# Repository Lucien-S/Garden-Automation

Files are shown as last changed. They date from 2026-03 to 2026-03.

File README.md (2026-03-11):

# Garden Automation — ESP32

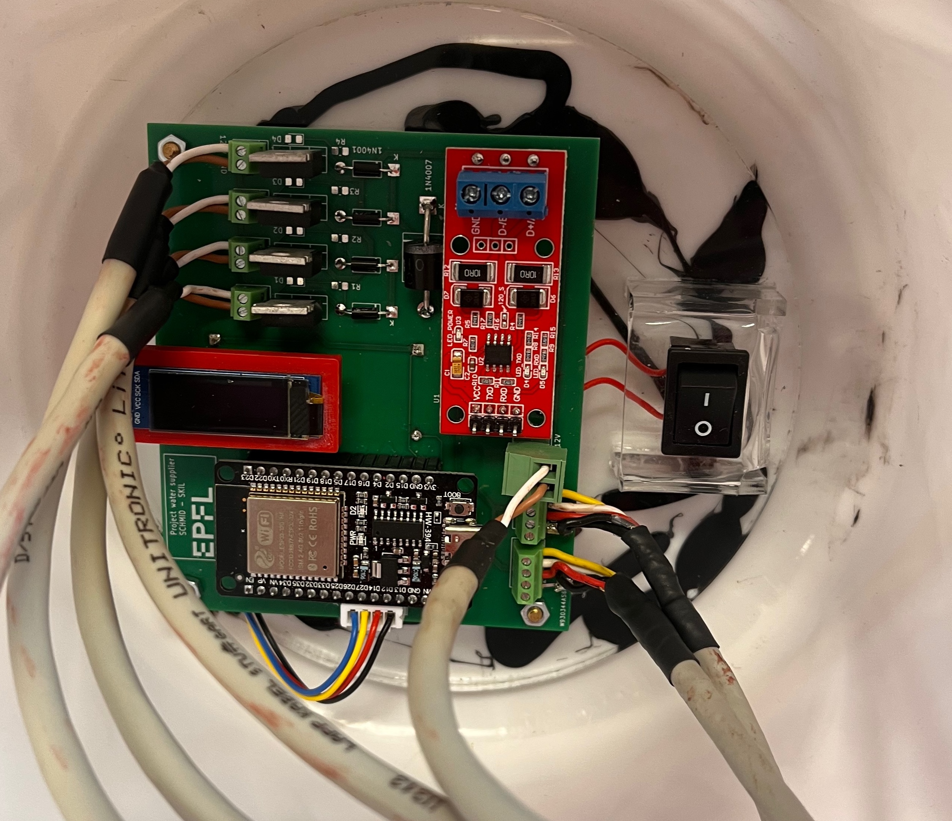
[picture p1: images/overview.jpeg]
PCB overview with cables to pumps and electrovannes


Automated garden watering system based on ESP32, soil moisture sensors (RS485/Modbus), solenoid valves, and MQTT over WiFi.

Youtube link: [ https://youtube.com/shorts/rQiWS8xde-I?feature=share ](https://youtu.be/8DQGsPcLfHw)

KiCad files are available in the folder /kicad

---

## Hardware

| Component | Details |
|---|---|
| MCU | ESP32-WROOM-32D |
| Moisture sensors | RS485 Modbus (x2), addresses 0x01 and 0x02 |
| Solenoid valves | 3× EV (EV1, EV2, EV3) driven via GPIO |
| Pump | 1× driven via GPIO |
| Display | SSD1306 OLED 128×32, I2C |
| Communication | WiFi SoftAP + MQTT |

### Pin Mapping

| Pin | Function |
|-----|---|
| GPIO 23 | Pump |
| GPIO 19 | EV1 |
| GPIO 22 | EV2 |
| GPIO 3 | EV3 |
| GPIO 32 | OLED SDA |
| GPIO 33 | OLED SCL |
| GPIO 16 | RS485 RX |
| GPIO 17 | RS485 TX |

---

## Software

### Dependencies

All libraries are loaded from `/Users/rascarcapac/Documents/Arduino/libraries` via `lib_extra_dirs` in `platformio.ini`.

| Library | Purpose |
|---|---|
| Adafruit SSD1306 | OLED display |
| Adafruit GFX | Graphics primitives |
| PubSubClient | MQTT client |
| RTClib | DS3231 RTC (optional, not used in this branch) |

### platformio.ini

```ini
[env:esp32dev]
platform = espressif32
board = esp32dev
framework = arduino

monitor_speed = 115200
monitor_echo = yes
monitor_filters = send_on_enter

lib_extra_dirs = /Users/rascarcapac/Documents/Arduino/libraries
```

---

## Architecture

### Serial communication

Two separate modes are used depending on context:

- **Wizard (setup)** — character-by-character read loop with `yield()` to feed the FreeRTOS watchdog. Blocking by design since it waits for human input.
- **Runtime (loop)** — non-blocking char-by-char buffer. A complete command is processed only when `\n` is received.

### Runtime commands (Serial or MQTT)

Format: `CMD` or `CMD:value`

| Command | Effect |
|---|---|
| `WATER:1` | Start watering cycle on EV1 |
| `WATER:2` | Start watering cycle on EV2 |
| `WATER:3` | Start watering cycle on EV3 |
| `STOP` | Stop active watering cycle immediately |
| `STATUS` | Print current state to Serial |
| `RESET_DAILY` | Reset daily water usage counter |

The same `processRuntimeCommand()` function handles both Serial and MQTT input.

### MQTT topics

| Topic | Direction | Content |
|---|---|---|
| `garden/valve/command` | subscribe | `WATER:1`, `STOP`, etc. |
| `garden/sensors/sensor1/humidity` | publish | float, e.g. `42.3` |
| `garden/sensors/sensor1/temperature` | publish | float |
| `garden/sensors/sensor2/humidity` | publish | float |
| `garden/sensors/sensor2/temperature` | publish | float |
| `garden/pump/state` | publish | `ON` or `OFF` |

### WiFi

The ESP32 runs as a **SoftAP** (access point), not a station. Other devices connect to it.

| Parameter | Value |
|---|---|
| SSID | `Colloc` |
| IP | `192.168.4.1` |
| MQTT broker expected at | `192.168.4.2` |

---

## Watering logic

- Watering triggers when a sensor reads below **30% humidity**
- Each valve has a **cooldown period** of 2 minutes between cycles
- A **daily water budget** is computed from reservoir size (10 L) divided by configured number of days
- Usage is persisted in NVS (flash) and survives reboots
- Maximum single cycle duration: 30 seconds

---

## Configuration wizard

On first boot (or if NVS is not calibrated), a serial wizard guides through:

1. Sensor calibration (dry / wet reference values)
2. Plumbing check
3. Sensor → valve mapping
4. Watering days configuration
5. Hardware test (each valve + pump for 5s)

Type `r` at any prompt to restart the wizard from the beginning.

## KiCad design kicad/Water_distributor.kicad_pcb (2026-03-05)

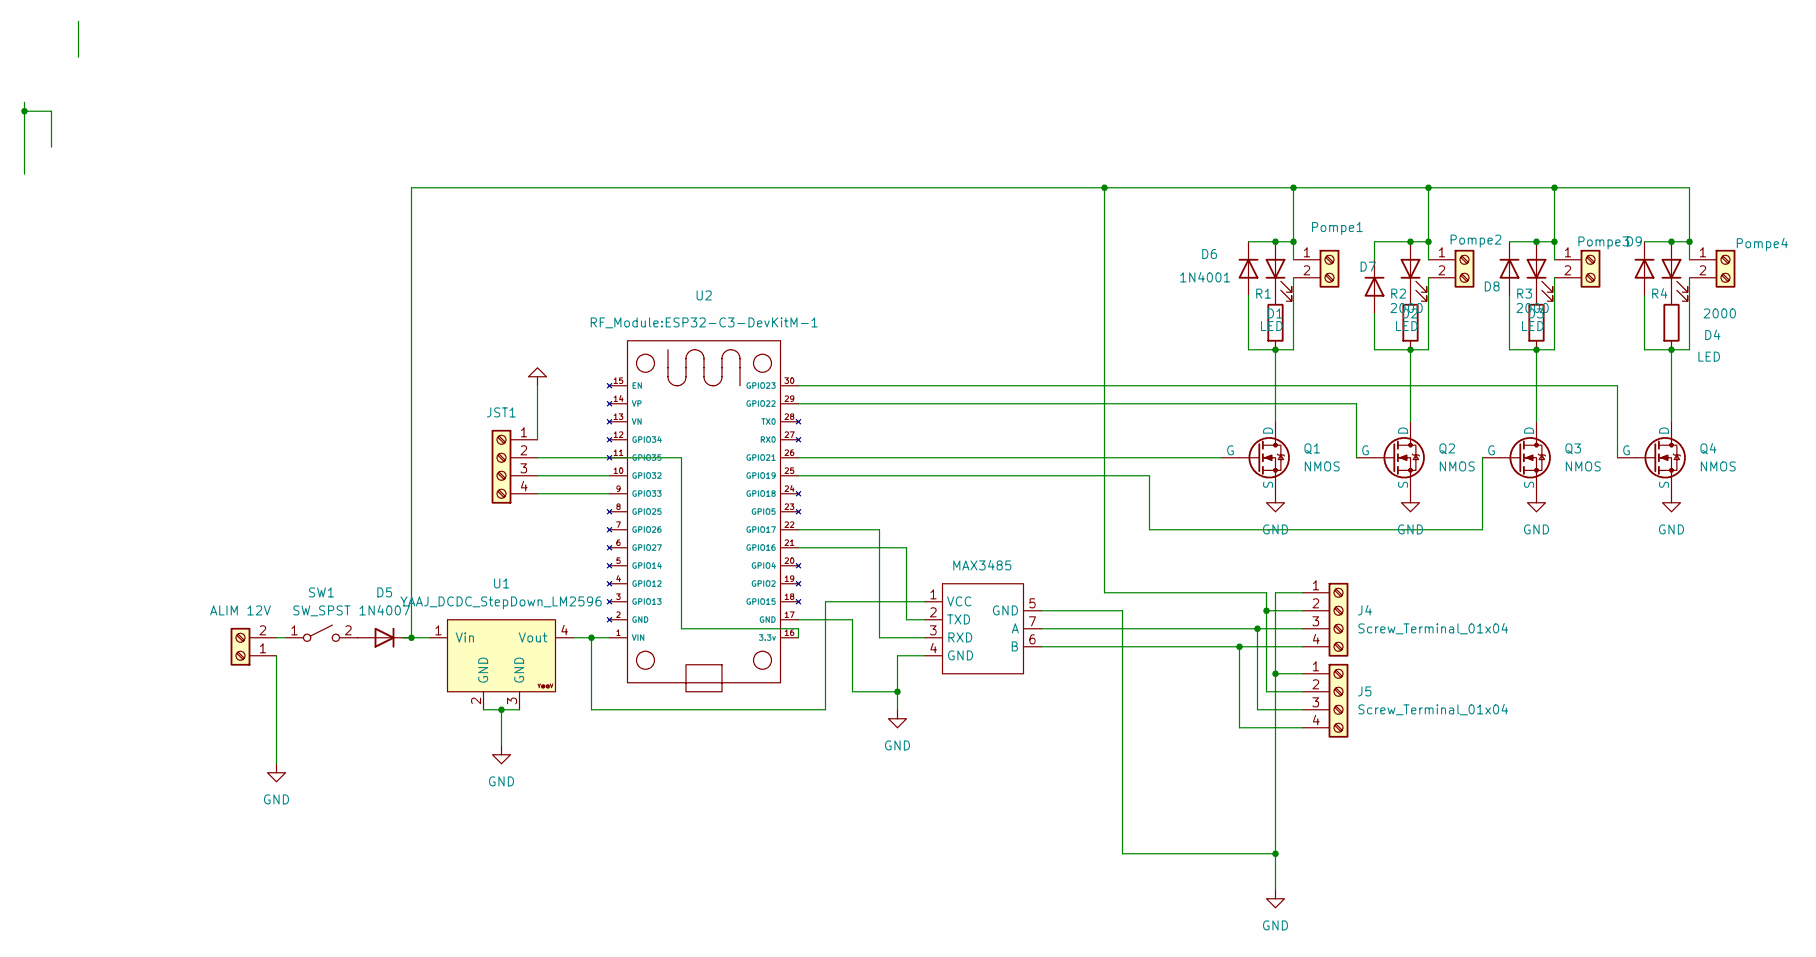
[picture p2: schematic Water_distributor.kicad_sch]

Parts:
D1, D2, D3, D4: LED; LED_0805_2012Metric_Pad1.15x1.40mm_HandSolder
D5: 1N4007; D_P600_R-6_P20.00mm_Horizontal
D6, D7, D8, D9: 1N4001; D_DO-41_SOD81_P10.16mm_Horizontal
J1: ALIM 12V; PhoenixContact_MCV_1,5_2-G-3.81_1x02_P3.81mm_Vertical
J4, J5: Screw_Terminal_01x04; TerminalBlock_Xinya_XY308-2.54-4P_1x04_P2.54mm_Horizontal
JST1: Screw_Terminal_01x04; JST_XH_B04B-XH-A_04x2.50mm_Straight
MAX3485: MAX3485
Pompe1, Pompe2, Pompe3, Pompe4: Screw_Terminal_01x02; TerminalBlock_Xinya_XY308-2.54-2P_1x02_P2.54mm_Horizontal
Q1, Q2, Q3, Q4: NMOS; TO-220-3_Vertical
R1, R2, R3, R4: 2000; R_0805_2012Metric_Pad1.20x1.40mm_HandSolder
SW1: SW_SPST; lever_switch
U1: YAAJ_DCDC_StepDown_LM2596; DCDC_LM2596
U2: ESP32-C3-DevKitM-1

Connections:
GND: J1.1, J4.1, J5.1, JST1.1 (GND), MAX3485.4 (GND), MAX3485.5 (GND), Q1.3 (S), Q2.3 (S), Q3.3 (S), Q4.3 (S), U1.2 (GND), U1.3 (GND), U2.17 (GND)
unnamed: D1.2 (A), D2.2 (A), D3.2 (A), D4.2 (A), D5.1 (K), D6.1 (K), D7.1 (K), D8.1 (K), D9.1 (K), J4.2, J5.2, Pompe1.1, Pompe2.1, Pompe3.1, Pompe4.1, U1.1 (Vin)
unnamed: D1.1 (K), R1.1
unnamed: D2.1 (K), R2.1
unnamed: D3.1 (K), R3.1
unnamed: D4.1 (K), R4.1
unnamed: D5.2 (A), SW1.2 (B)
unnamed: D6.2 (A), Pompe1.2, Q1.1 (D), R1.2
unnamed: D7.2 (A), Pompe2.2, Q2.1 (D), R2.2
unnamed: D8.2 (A), Pompe3.2, Q3.1 (D), R3.2
unnamed: D9.2 (A), Pompe4.2, Q4.1 (D), R4.2
unnamed: J1.2, SW1.1 (A)
unnamed: J4.3, J5.3, MAX3485.7 (A)
unnamed: J4.4, J5.4, MAX3485.6 (B)
unnamed: JST1.4 (Pin_1), U2.9 (GPIO33)
unnamed: JST1.3 (Pin_2), U2.10 (GPIO32)
unnamed: JST1.2 (Vin), U2.16 (3.3v)
unnamed: MAX3485.3 (RXD), U2.22 (GPIO17)
unnamed: MAX3485.2 (TXD), U2.21 (GPIO16)
unnamed: MAX3485.1 (VCC), U1.4 (Vout), U2.1 (VIN)
unnamed: Q1.2 (G), U2.26 (GPIO21)
unnamed: Q2.2 (G), U2.29 (GPIO22)
unnamed: Q3.2 (G), U2.25 (GPIO19)
unnamed: Q4.2 (G), U2.30 (GPIO23)

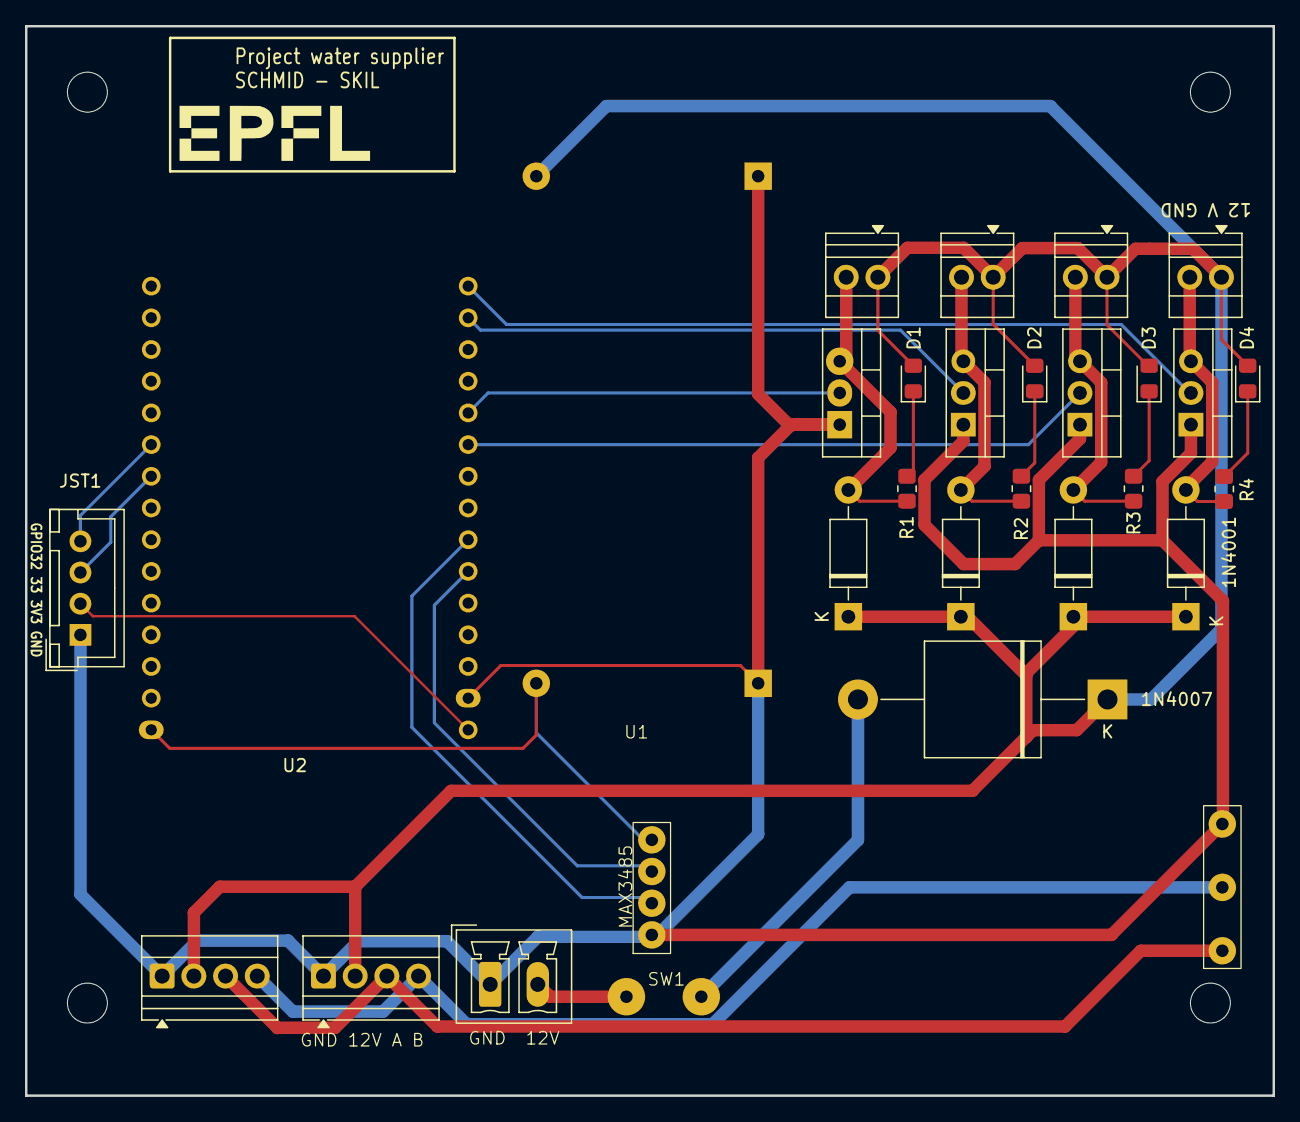
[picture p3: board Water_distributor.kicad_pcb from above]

Board: 2 copper layers, 100.0 x 85.7 mm, 29 parts (0 on the bottom side), 24 nets.

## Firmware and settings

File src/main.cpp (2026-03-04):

// ============================================================
// GARDEN CONTROLLER — ESP32
// Serial robustness:
//   • Wizard (setup)  → Serial.setTimeout(30000) + readStringUntil('\n')
//     Le blocage est VOULU ici, on attend l'humain.
//   • Loop (runtime)  → char-by-char buffer non-bloquant
//     Commandes ex: "WATER:1", "STOP", "STATUS"
//
// Supprimé : setjmp/longjmp (UB avec objets C++), goto (UB cross-declaration)
// Remplacé par : do/while(restart) + boucles while + fonctions helper
// ============================================================

#include <Arduino.h>
#include <WiFi.h>
#include <PubSubClient.h>
#include <HardwareSerial.h>
#include <Wire.h>
#include <Adafruit_GFX.h>
#include <Adafruit_SSD1306.h>
#include <SPI.h>
#include <driver/gpio.h>
#include <cstdio>
#include <Preferences.h>
#include "RTClib.h"

// ============================================================
// CONSTANTS
// ============================================================
namespace cfg {
    constexpr char     AP_SSID[]          = "Colloc";
    constexpr char     AP_PASSWORD[]      = "essai1234";
    constexpr size_t   AP_PASSWORD_LEN    = sizeof(AP_PASSWORD) - 1;
    const     IPAddress AP_LOCAL_IP       = IPAddress(192,168,4,1);
    const     IPAddress AP_GATEWAY        = IPAddress(192,168,4,1);
    const     IPAddress AP_SUBNET         = IPAddress(255,255,255,0);

    constexpr char     MQTT_HOST[]        = "192.168.4.2";
    constexpr uint16_t MQTT_PORT          = 1883;
    constexpr char     MQTT_CLIENT_ID[]   = "esp32-garden";
    constexpr char     MQTT_CMD_TOPIC[]   = "garden/valve/command";
    constexpr unsigned long PUBLISH_MS    = 300000UL;  // 5 min

    constexpr byte     SENSOR1_ADDR       = 0x01;
    constexpr byte     SENSOR2_ADDR       = 0x02;

    constexpr uint8_t  OLED_SDA           = 32;
    constexpr uint8_t  OLED_SCL           = 33;
    constexpr int8_t   OLED_RESET         = -1;
    constexpr uint8_t  SCREEN_W           = 128;
    constexpr uint8_t  SCREEN_H           = 32;

    constexpr uint8_t  PUMP_PIN           = 23;
    constexpr uint8_t  EV1_PIN            = 19;
    constexpr uint8_t  EV2_PIN            = 22;
    constexpr uint8_t  EV3_PIN            = 3;

    constexpr uint8_t  RTC_SDA            = 25;
    constexpr uint8_t  RTC_SCL            = 26;

    constexpr float    HUMIDITY_THRESHOLD = 30.0f;
    constexpr unsigned long PRIME_DURATION_MS = 15000UL;  // amorçage pompe avant ouverture EV
    constexpr unsigned long WATER_DUR_MS      = 30000UL;
    constexpr unsigned long COOLDOWN_MS       = 120000UL;
    constexpr unsigned long SENSOR_READ_MS = 30000UL;  // lecture capteurs
    constexpr unsigned long SENSOR_LOG_MS  = 60000UL;  // affichage série
}

// ============================================================
// STRUCTS
// ============================================================
struct SensorReading {
    float humidity    = 0.0f;
    float temperature = 0.0f;
    bool  ok          = false;
};

struct CalibData {
    float s1Dry = 0.0f, s1Wet = 100.0f;
    float s2Dry = 0.0f, s2Wet = 100.0f;
};

struct Config {
    uint8_t evMaskSensor1 = 0b001;  // bitmask: bit0=EV1 bit1=EV2 bit2=EV3
    uint8_t evMaskSensor2 = 0b100;
    uint8_t wateringDays  = 10;
};

struct WateringState {
    bool          pumpActive               = false;
    bool          isPriming               = false;  // true pendant les 15 s d'amorçage
    uint8_t       activeValveMask          = 0;
    uint8_t       activeZone               = 0;    // 1 = capteur1, 2 = capteur2
    unsigned long cycleStartTime           = 0;
    unsigned long primingStartTime         = 0;
    unsigned long maxDuration              = 0;
    unsigned long lastCycleTime[3]         = {0, 0, 0};
};

// ============================================================
// GLOBALS
// ============================================================
Preferences      prefs;
HardwareSerial   rs485Serial(2);
Adafruit_SSD1306 display(cfg::SCREEN_W, cfg::SCREEN_H, &Wire, cfg::OLED_RESET);
WiFiClient       wifiClient;
PubSubClient     mqttClient(wifiClient);
TwoWire          rtcWire(1);   // I2C bus 1 pour la RTC (SDA=25, SCL=26)
RTC_DS3231       rtc;
bool             rtcAvailable = false;

byte          response[20];
unsigned long lastPublish      = 0;
unsigned long lastSensorRead   = 0;
unsigned long lastSensorLog    = 0;
unsigned long lastDailyCheck   = 0;
unsigned long lastAlertTime    = 0;
unsigned long lastMqttAttempt  = 0;
bool   pendingPostWateringPublish = false;
CalibData     calibData;
Config        config;
WateringState wateringState;

// Buffer pour commandes série non-bloquantes dans loop()
static char   serialBuf[64];
static uint8_t serialBufIdx = 0;

// ============================================================
// NVS
// ============================================================
constexpr char NVS_NS[]         = "garden";
constexpr char NVS_CALIBRATED[] = "calibrated";
constexpr char NVS_S1_DRY[]     = "s1_dry";
constexpr char NVS_S1_WET[]     = "s1_wet";
constexpr char NVS_S2_DRY[]     = "s2_dry";
constexpr char NVS_S2_WET[]     = "s2_wet";
constexpr char NVS_EV_MASK1[]   = "ev_mask1";
constexpr char NVS_EV_MASK2[]   = "ev_mask2";
constexpr char NVS_WATER_DAYS[] = "water_days";
constexpr char NVS_DAILY_USED_Z1[] = "used_z1";
constexpr char NVS_DAILY_USED_Z2[] = "used_z2";
constexpr char NVS_LAST_DAY[]      = "last_day";

void loadNVS() {
    prefs.begin(NVS_NS, true);
    calibData.s1Dry     = prefs.getFloat(NVS_S1_DRY, 0.0f);
    calibData.s1Wet     = prefs.getFloat(NVS_S1_WET, 100.0f);
    calibData.s2Dry     = prefs.getFloat(NVS_S2_DRY, 0.0f);
    calibData.s2Wet     = prefs.getFloat(NVS_S2_WET, 100.0f);
    config.evMaskSensor1 = prefs.getUChar(NVS_EV_MASK1, 0b001);
    config.evMaskSensor2 = prefs.getUChar(NVS_EV_MASK2, 0b100);
    config.wateringDays = prefs.getUChar(NVS_WATER_DAYS, 10);
    prefs.end();
}

void saveNVS() {
    prefs.begin(NVS_NS, false);
    prefs.putFloat(NVS_S1_DRY,    calibData.s1Dry);
    prefs.putFloat(NVS_S1_WET,    calibData.s1Wet);
    prefs.putFloat(NVS_S2_DRY,    calibData.s2Dry);
    prefs.putFloat(NVS_S2_WET,    calibData.s2Wet);
    prefs.putUChar(NVS_EV_MASK1,   config.evMaskSensor1);
    prefs.putUChar(NVS_EV_MASK2,   config.evMaskSensor2);
    prefs.putUChar(NVS_WATER_DAYS, config.wateringDays);
    prefs.putBool(NVS_CALIBRATED,  true);
    prefs.end();
}

bool isCalibrated() {
    prefs.begin(NVS_NS, true);
    bool v = prefs.getBool(NVS_CALIBRATED, false);
    prefs.end();
    return v;
}

float getDailyUsedL(uint8_t zone) {
    prefs.begin(NVS_NS, true);
    const char* key = (zone == 1) ? NVS_DAILY_USED_Z1 : NVS_DAILY_USED_Z2;
    float v = prefs.isKey(key) ? prefs.getFloat(key, 0.0f) : 0.0f;
    prefs.end();
    return v;
}

void setDailyUsedL(uint8_t zone, float v) {
    prefs.begin(NVS_NS, false);
    prefs.putFloat(zone == 1 ? NVS_DAILY_USED_Z1 : NVS_DAILY_USED_Z2, v);
    prefs.end();
}

void resetDailyUsedIfNewDay() {
    if (!rtcAvailable) return;  // sans RTC on ne connait pas le jour
    uint8_t today = rtc.now().day();
    prefs.begin(NVS_NS, false);
    uint8_t last = prefs.getUChar(NVS_LAST_DAY, 0);
    if (last != today) {
        prefs.putFloat(NVS_DAILY_USED_Z1, 0.0f);
        prefs.putFloat(NVS_DAILY_USED_Z2, 0.0f);
        prefs.putUChar(NVS_LAST_DAY, today);
        Serial.println("Nouveau jour: budgets zones remis a zero.");
    }
    prefs.end();
}

// Forward declarations (définies plus bas)
static String  evMaskToStr(uint8_t mask);
static float   computeZoneMax(uint8_t zone);
void publishAlert(const char* msg);
void publishPostWateringStatus();

// ============================================================
// SERIAL — WIZARD (bloquant, utilisé dans setup() uniquement)
// ============================================================
// Principe : Serial.setTimeout(30000) défini une fois dans setup().
// readStringUntil('\n') bloque jusqu'au '\n' ou timeout 30s.
// trim() gère \r\n, \n, ou pas de terminateur selon réglage IDE.

// Vide le buffer entrant
void clearSerial() {
    while (Serial.available()) Serial.read();
    delay(10); // laisse les derniers octets arriver
    while (Serial.available()) Serial.read();
}

// Lit une ligne. Retourne "" si timeout ou ligne vide.
// À utiliser UNIQUEMENT depuis setup()/wizard.
static String wizReadLine() {
    String s = "";
    unsigned long start = millis();
    while (millis() - start < 30000) {
        while (Serial.available()) {
            char c = (char)Serial.read();
            if (c == '\n' || c == '\r') {
                s.trim();
                if (s.length() > 0) {
                    Serial.println();  // newline après la saisie
                    delay(5);
                    while (Serial.available()) {
                        char next = (char)Serial.peek();
                        if (next == '\r' || next == '\n') Serial.read();
                        else break;
                    }
                    return s;
                }
                // s still empty: lone \r or \n before content, keep reading
            } else {
                s += c;
                Serial.write(c);  // echo du caractère → l'utilisateur voit ce qu'il tape
            }
        }
        yield();    // nourrit le watchdog FreeRTOS, évite le reboot silencieux
        delay(10);
    }
    s.trim();
    return s;
}

// Attend un caractère unique. Ignore les CR/LF isolés.
// Retourne '\0' après 30 s de silence.
static char wizReadChar() {
    unsigned long start = millis();
    while (millis() - start < 30000) {
        if (Serial.available()) {
            char c = (char)Serial.read();
            if (c != '\r' && c != '\n') {
                // Drain any trailing CR/LF
                delay(10);
                while (Serial.available()) {
                    char nx = (char)Serial.peek();
                    if (nx == '\r' || nx == '\n') Serial.read();
                    else break;
                }
                return (char)tolower(c);
            }
            // Lone CR or LF — ignore, keep waiting
        }
        yield();
        delay(10);
    }
    return '\0';
}

// Demande o/n. Retourne true si 'o', false si 'n'.
// Répète jusqu'à réponse valide ou maxTries dépassé (renvoie defaultVal).
static bool wizAskON(const char* question, bool defaultVal = false) {
    for (uint8_t attempt = 0; attempt < 5; attempt++) {
        Serial.print(question);
        Serial.print(" (o/n) : ");
        char c = wizReadChar();
        if (c == '\0') { Serial.println("  (rien recu, reessayez)"); continue; }
        if (c == 'o') { Serial.println("o"); return true;  }
        if (c == 'n') { Serial.println("n"); return false; }
        Serial.printf("  -> '%c' non reconnu\n", c);
    }
    Serial.printf("  -> Defaut : %s\n", defaultVal ? "oui" : "non");
    return defaultVal;
}

// Lit un entier. Répète si invalide.
static int wizReadInt(const char* prompt, int minVal, int maxVal) {
    while (true) {
        Serial.print(prompt);
        String s = wizReadLine();
        if (s.length() == 0) { Serial.println("  (rien recu, reessayez)"); continue; }
        // toInt() retourne 0 si non-numérique → on vérifie que le 1er char est un chiffre
        if (!isDigit(s[0]) && !(s[0] == '-')) { Serial.println("  -> Pas un nombre."); continue; }
        int v = s.toInt();
        if (v < minVal || v > maxVal) {
            Serial.printf("  -> Hors plage [%d-%d]\n", minVal, maxVal);
            continue;
        }
        Serial.printf("  -> %d\n", v);
        return v;
    }
}

// Lit un masque d'EV. Accepte "1", "2", "3", "1/2", "1/3", "2/3", "1/2/3".
// Retourne un bitmask (bit0=EV1, bit1=EV2, bit2=EV3).
static uint8_t wizReadEVMask(const char* prompt) {
    while (true) {
        Serial.print(prompt);
        String s = wizReadLine();
        if (s.length() == 0) { Serial.println("  (rien recu, reessayez)"); continue; }
        uint8_t mask = 0;
        bool valid = true;
        int start = 0;
        for (int i = 0; i <= (int)s.length(); i++) {
            if (i == (int)s.length() || s[i] == '/') {
                String token = s.substring(start, i);
                token.trim();
                if (token.length() > 0) {
                    int v = token.toInt();
                    if (v >= 1 && v <= 3) mask |= (1u << (v - 1));
                    else { valid = false; break; }
                }
                start = i + 1;
            }
        }
        if (!valid || mask == 0) {
            Serial.println("  -> Format invalide. Ex: 1  ou  1/2  ou  2/3");
            continue;
        }
        Serial.printf("  -> %s\n", evMaskToStr(mask).c_str());
        return mask;
    }
}

// ============================================================
// SERIAL — RUNTIME (non-bloquant, utilisé dans loop())
// ============================================================
// Principe : on lit octet par octet dans le buffer hardware (64 bytes).
// Quand '\n' détecté → ligne complète → on la traite.
// Jamais de blocage, jamais de delay.

// Forward declarations
void processRuntimeCommand(const char* cmd);

void handleSerialRuntime() {
    while (Serial.available()) {
        char c = (char)Serial.read();
        if (c == '\r') continue; // ignore CR
        if (c == '\n') {
            serialBuf[serialBufIdx] = '\0';
            if (serialBufIdx > 0) {
                processRuntimeCommand(serialBuf);
            }
            serialBufIdx = 0;
        } else if (serialBufIdx < sizeof(serialBuf) - 1) {
            serialBuf[serialBufIdx++] = c;
        } else {
            // Buffer plein → flush et ignore
            serialBufIdx = 0;
            Serial.println("[SERIAL] Ligne trop longue, ignoree.");
        }
    }
}

// ============================================================
// FORWARD DECLARATIONS
// ============================================================
void runTestMode();
void startWateringCycle(uint8_t valveMask, uint8_t zone, float zoneMaxL);
void stopWateringCycle();
SensorReading readSensorRaw(byte address);
void printStatus();

// ============================================================
// COMMANDES RUNTIME (depuis Serial ou MQTT — même parser)
// Format : "CMD" ou "CMD:valeur"
// ============================================================
void processRuntimeCommand(const char* raw) {
    // Copie pour pouvoir modifier
    char buf[64];
    strncpy(buf, raw, sizeof(buf) - 1);
    buf[sizeof(buf)-1] = '\0';

    // Séparer cmd:valeur
    char* sep = strchr(buf, ':');
    char* cmd = buf;
    char* val = nullptr;
    if (sep) {
        *sep = '\0';
        val = sep + 1;
    }

    // Tout en majuscules pour comparaison insensible à la casse
    for (char* p = cmd; *p; p++) *p = toupper(*p);

    if (strcmp(cmd, "WATER") == 0 && val) {
        uint8_t zone = (uint8_t)atoi(val);
        if (zone == 1)      startWateringCycle(config.evMaskSensor1, 1, computeZoneMax(1));
        else if (zone == 2) startWateringCycle(config.evMaskSensor2, 2, computeZoneMax(2));
        else Serial.println("[CMD] Zone invalide (1=capteur1, 2=capteur2)");
    }
    else if (strcmp(cmd, "STOP") == 0) {
        stopWateringCycle();
    }
    else if (strcmp(cmd, "STATUS") == 0) {
        printStatus();
    }
    else if (strcmp(cmd, "RESET_DAILY") == 0) {
        setDailyUsedL(1, 0.0f);
        setDailyUsedL(2, 0.0f);
        Serial.println("[CMD] Compteurs journaliers remis a zero.");
    }
    else {
        Serial.printf("[CMD] Inconnu : '%s'. Cmds: WATER:1, WATER:2, STOP, STATUS, RESET_DAILY\n", raw);
    }
}

// Même entrée pour MQTT
void mqttCallback(char* topic, byte* payload, unsigned int length) {
    char buf[64] = {0};
    memcpy(buf, payload, min((size_t)length, sizeof(buf) - 1));
    processRuntimeCommand(buf);
}

// ============================================================
// HELPERS
// ============================================================
static uint8_t countBits(uint8_t mask) {
    uint8_t n = 0;
    while (mask) { n += mask & 1u; mask >>= 1; }
    return n;
}

// Budget journalier d'une zone, proportionnel à son nombre d'EV.
// Ex: 3 EV total, zone1=2 EV → zone1 reçoit 2/3 du budget total.
static float computeZoneMax(uint8_t zone) {
    float    totalMax = 10.0f / (float)config.wateringDays;
    uint8_t  ev1      = countBits(config.evMaskSensor1);
    uint8_t  ev2      = countBits(config.evMaskSensor2);
    uint8_t  total    = ev1 + ev2;
    if (total == 0) return totalMax / 2.0f;
    return totalMax * (float)(zone == 1 ? ev1 : ev2) / (float)total;
}

// Vrai si on est dans une fenêtre d'arrosage automatique (6h ou 20h)
static bool isWateringWindow() {
    if (!rtcAvailable) return true;  // sans RTC: toujours actif
    uint8_t h = rtc.now().hour();
    return (h == 6 || h == 20);
}

// Vrai si on est dans la session du soir (20h+), utilisé pour emprunter budget Z2
static bool isEveningSession() {
    if (!rtcAvailable) return false;
    return rtc.now().hour() >= 20;
}

// Convertit un masque en chaîne lisible: 0b011 → "EV1/EV2"
static String evMaskToStr(uint8_t mask) {
    String s = "";
    for (uint8_t i = 0; i < 3; i++) {
        if (mask & (1u << i)) {
            if (s.length() > 0) s += "/";
            s += "EV" + String(i + 1);
        }
    }
    if (s.length() == 0) s = "none";
    return s;
}

// ============================================================
// GPIO / VALVES / PUMP
// ============================================================
void forceGPIOMode(uint8_t pin) {
    gpio_config_t io_conf = {};
    io_conf.intr_type    = GPIO_INTR_DISABLE;
    io_conf.mode         = GPIO_MODE_OUTPUT;
    io_conf.pin_bit_mask = (1ULL << pin);
    io_conf.pull_down_en = GPIO_PULLDOWN_DISABLE;
    io_conf.pull_up_en   = GPIO_PULLUP_DISABLE;
    gpio_config(&io_conf);
    gpio_set_level(static_cast<gpio_num_t>(pin), 0);
}

void setGPIO(uint8_t pin, bool state) {
    gpio_set_level(static_cast<gpio_num_t>(pin), state ? 1 : 0);
}

void openValves(uint8_t mask) {
    const uint8_t pins[] = {cfg::EV1_PIN, cfg::EV2_PIN, cfg::EV3_PIN};
    for (uint8_t i = 0; i < 3; i++) {
        if (mask & (1u << i)) setGPIO(pins[i], true);
    }
    Serial.printf("%s OUVERTES\n", evMaskToStr(mask).c_str());
}

void closeValves(uint8_t mask) {
    const uint8_t pins[] = {cfg::EV1_PIN, cfg::EV2_PIN, cfg::EV3_PIN};
    for (uint8_t i = 0; i < 3; i++) {
        if (mask & (1u << i)) setGPIO(pins[i], false);
    }
}

void closeAllValves() {
    closeValves(0b111);
}

void activatePump() {
    setGPIO(cfg::PUMP_PIN, true);
    wateringState.pumpActive = true;
    Serial.println("Pompe ON");
}

void deactivatePump() {
    setGPIO(cfg::PUMP_PIN, false);
    wateringState.pumpActive = false;
    Serial.println("Pompe OFF");
}

// ============================================================
// MODBUS / SENSOR
// ============================================================
uint16_t modbusCRC(const byte* data, uint8_t length) {
    uint16_t crc = 0xFFFF;
    for (uint8_t i = 0; i < length; i++) {
        crc ^= data[i];
        for (uint8_t j = 0; j < 8; j++)
            crc = (crc & 0x0001) ? ((crc >> 1U) ^ 0xA001) : (crc >> 1U);
    }
    return crc;
}

SensorReading readSensorRaw(byte address) {
    SensorReading reading;
    byte request[] = {address, 0x03, 0x00, 0x00, 0x00, 0x04, 0x00, 0x00};
    uint16_t crc = modbusCRC(request, 6);
    request[6] = crc & 0xFF;
    request[7] = (crc >> 8) & 0xFF;
    rs485Serial.write(request, sizeof(request));
    rs485Serial.flush();
    delay(150);
    int len = rs485Serial.readBytes(response, sizeof(response));
    if (len >= 7 && response[0] == address && response[1] == 0x03) {
        reading.humidity    = ((response[3] << 8) | response[4]) / 10.0f;
        reading.temperature = static_cast<int16_t>((response[5] << 8) | response[6]) / 10.0f;
        reading.ok = true;
    }
    return reading;
}

float rawToPercent(float raw, float dry, float wet) {
    if (wet == dry) return raw;
    float pct = (raw - dry) / (wet - dry) * 100.0f;
    if (pct < 0.0f)   pct = 0.0f;
    if (pct > 100.0f) pct = 100.0f;
    return pct;
}
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
void loop() {
    unsigned long now = millis();

    // 1. Commandes série (non-bloquant — char par char)
    handleSerialRuntime();

    // 2. MQTT
    if (!mqttClient.connected()) tryConnectMqtt();
    mqttClient.loop();

    // 3. Timeout arrosage (vérifié à chaque itération)
    checkWateringCycleTimeout();

    // 3b. Publication post-arrosage (déclenché par stopWateringCycle)
    if (pendingPostWateringPublish) {
        pendingPostWateringPublish = false;
        publishPostWateringStatus();
    }

    // 4. Remise à zéro journalière via RTC (toutes les 60 s)
    if (now - lastDailyCheck >= 60000UL) {
        lastDailyCheck = now;
        resetDailyUsedIfNewDay();
    }

    // 5. Lecture capteurs toutes les 30 s
    if (now - lastSensorRead >= cfg::SENSOR_READ_MS) {
        lastSensorRead = now;
        bool verbose = (now - lastSensorLog >= cfg::SENSOR_LOG_MS);
        if (verbose) lastSensorLog = now;

        SensorReading s1 = readSensor(cfg::SENSOR1_ADDR, calibData.s1Dry, calibData.s1Wet, verbose);
        delay(200);
        SensorReading s2 = readSensor(cfg::SENSOR2_ADDR, calibData.s2Dry, calibData.s2Wet, verbose);

        checkAutomaticWatering(s1, s2);
        updateDisplay(s1, s2);

        if (now - lastPublish >= cfg::PUBLISH_MS) {
            publishSensorReadings(1, s1);
            publishSensorReadings(2, s2);
            publishPumpState(wateringState.pumpActive);
            lastPublish = now;
        }
    }

    delay(100);
}

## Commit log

2026-03-02 fix: serial wizard input not received in PlatformIO monitor
    - platformio.ini: add monitor_filters=send_on_enter and monitor_eol=CRLF
    so the serial monitor buffers input and sends \r\n on Enter
    - src/main.cpp: wizReadLine() now accepts \r or \n as line terminator
    and drains trailing CR/LF pairs (\r\n), making it robust against
    any serial monitor line ending setting
    [main.cpp]
2026-03-02 fix: serial wizard input not received in PlatformIO monitor
    Root cause: EV3_PIN uses GPIO3 which is also UART0 RX. Calling
    forceGPIOMode(EV3_PIN) before the wizard drove GPIO3 LOW as an
    output, making Serial.available() always return 0.
    Fix:
    - Defer forceGPIOMode(EV3_PIN) to after runCalibrationWizard()
    so GPIO3 stays as UART0 RX during the entire wizard
    - wizReadChar(): reads first byte directly without needing a line
    terminator, robust to any serial monitor EOL setting
    - wizReadLine(): accepts both \r and \n as line terminators
    - platformio.ini: removed incorrect USB CDC build flags and
    monitor filters that were breaking serial input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
    [main.cpp]
2026-03-02 fix: add character echo in wizReadLine for visual feedback
    Without local echo in the serial monitor, the user couldn't see
    what they were typing. wizReadLine now echoes each received
    character back and prints a newline on Enter, so input is visible.
    [main.cpp]
2026-03-02 feat: support multiple valves per sensor (bitmask)
    Config now stores evMaskSensor1/evMaskSensor2 (bitmask, bit0=EV1).
    Wizard accepts inputs like "1/2" or "3". openValves(mask) opens all
    valves simultaneously. Budget tracked globally; WATER:1/WATER:2 map
    to sensor zones, not individual valve numbers.
2026-03-02 feat: RTC DS3231, per-zone budget, watering windows, MQTT alerts
    - Integrate DS3231 RTC on second I2C bus (SDA=25, SCL=26)
    - Wizard time-set step (confirm / correct / manual entry)
    - Per-zone daily water budget (NVS keys used_z1 / used_z2)
    - Budget proportional to EV count per zone; Z1 can borrow Z2 surplus in evening
    - Watering windows gate: auto-arrosage only at 06h and 20h
    - Daily reset via RTC (NVS last_day key)
    - Reduce sensor serial log to 60 s, MQTT publish to 5 min
    - MQTT alert on garden/alert/soif when zone is thirsty
    - Post-watering MQTT publish (sensors + budget)
    - Fix NVS NOT_FOUND error with isKey() guard
    - Fix budget overcounting by capping to maxDuration
    - Add 30 s cooldown be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
    [main.cpp]
2026-03-04 feat: pump priming phase before valve open (15s)
2026-03-05 Adding KiCad info
2026-03-05 Zip and kicad files
    All layers, schematics and footprints are available.
    [Water_distributor.kicad_pcb, Water_distributor.kicad_sch]
2026-03-11 chore: move KiCad files and .command to kicad/ folder
    [Water_distributor.kicad_pcb, Water_distributor.kicad_sch]
2026-03-11 docs: fix KiCad folder path in README (/include -> /kicad)
2026-03-11 docs: add project photo and fix KiCad folder path
